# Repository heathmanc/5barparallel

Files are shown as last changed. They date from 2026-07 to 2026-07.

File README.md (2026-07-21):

# Vision-Guided 5-Bar Bung-Cover Robot

Python + OpenCV control for a vision-guided **5-bar parallel-SCARA** pick-and-place
robot that installs plastic battery bung covers into the vent holes of a Group 31
battery on an indexing conveyor. An overhead camera detects holes and loose covers;
Python solves the 5-bar inverse kinematics, validates the target against the
workspace/singularity guard, and hands one pick/place job to a CompactLogix PLC.

See [`Claude.md`](Claude.md) for the full design, the verified geometry, and the
hardware/software responsibility split.

## Screenshots

A PySide6 dark-theme HMI. The **Vision** tab is the main run screen — detected
vent holes (numbered) and loose covers (green = reachable and correctly sized,
red = outside the clean work zone), with live drive / home / PLC / camera status
and the automatic pick-place cycle behind **Start**.

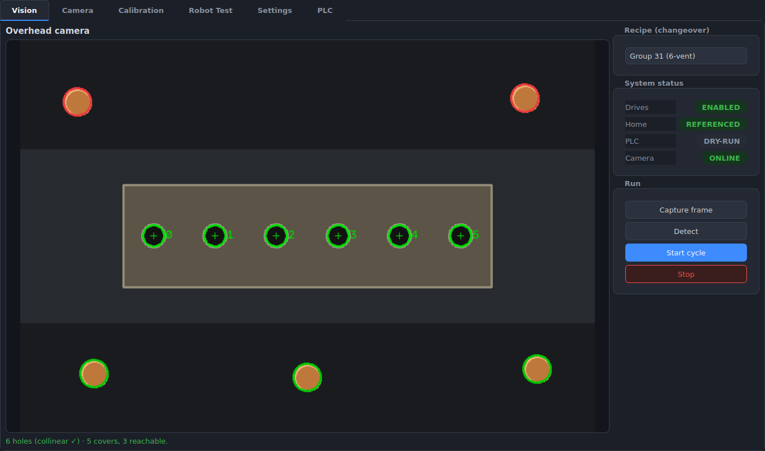
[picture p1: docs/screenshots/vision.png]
Vision tab


|  |  |
|---|---|
| **Calibration** — click known points, fit a per-recipe pixel→robot homography (RMS residual reported) | **Camera** — Basler imaging controls with a live preview |
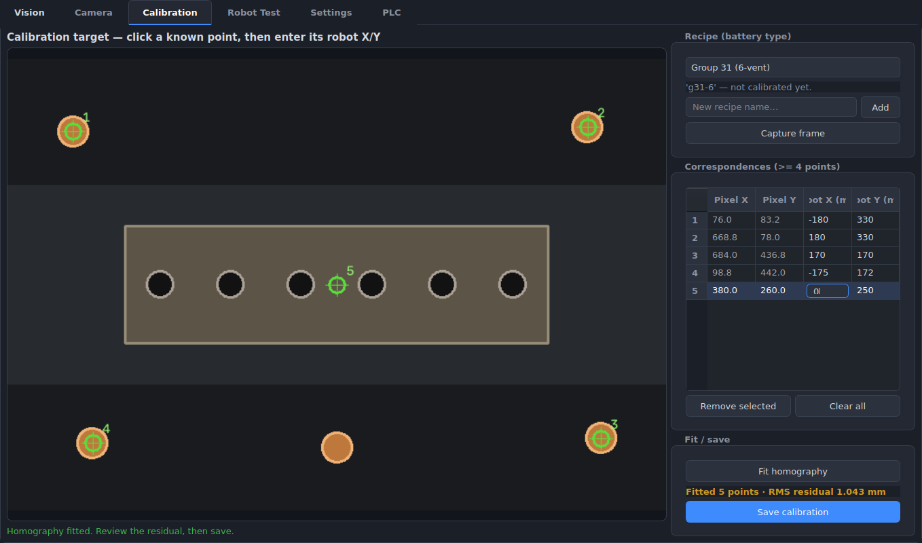
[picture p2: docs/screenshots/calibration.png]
Calibration tab
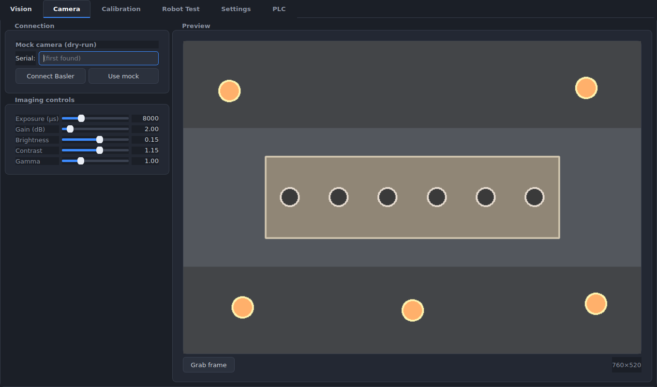
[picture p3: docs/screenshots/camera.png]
Camera tab
|  |  |
| **Robot Test** — reference, teach home, and jog (every move workspace-validated) | **Settings** — geometry + workspace-guard thresholds, re-validated on apply |
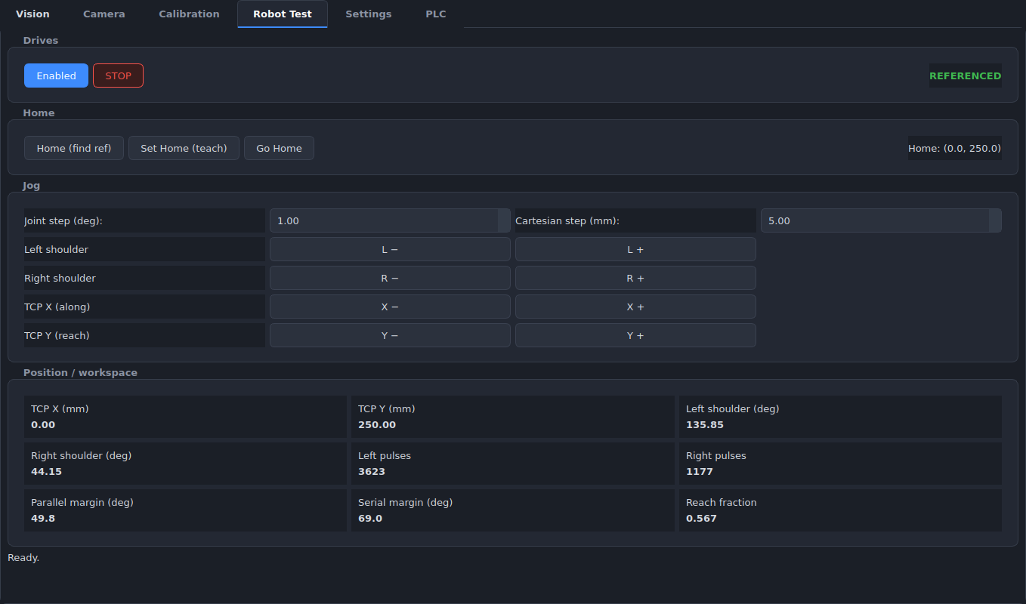
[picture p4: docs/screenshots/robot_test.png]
Robot Test tab
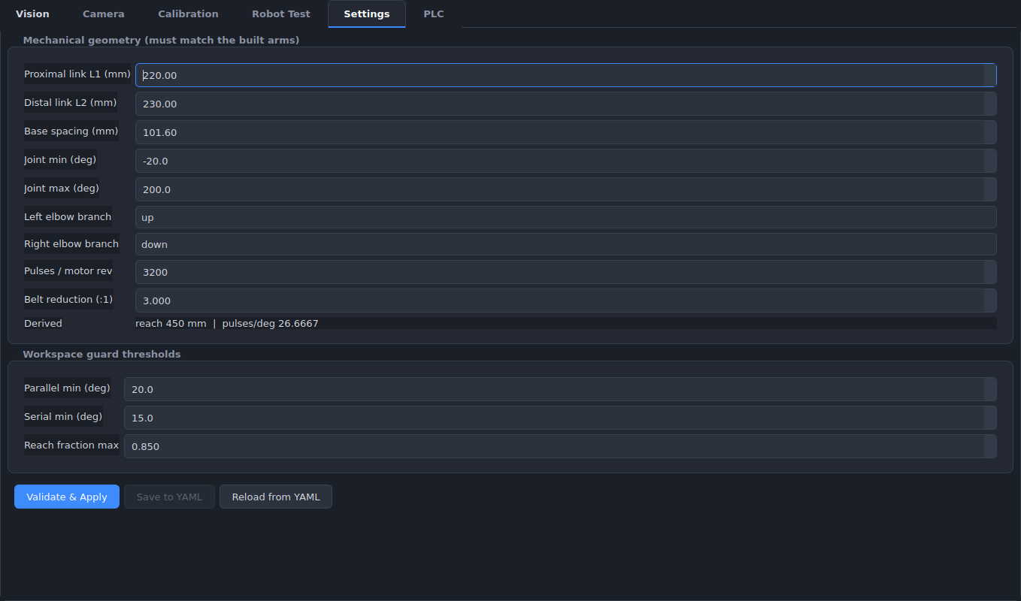
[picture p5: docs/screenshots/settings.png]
Settings tab
|  |  |
| **PLC** — connect a driver at runtime + the full tag contract the Studio 5000 program must implement |  |
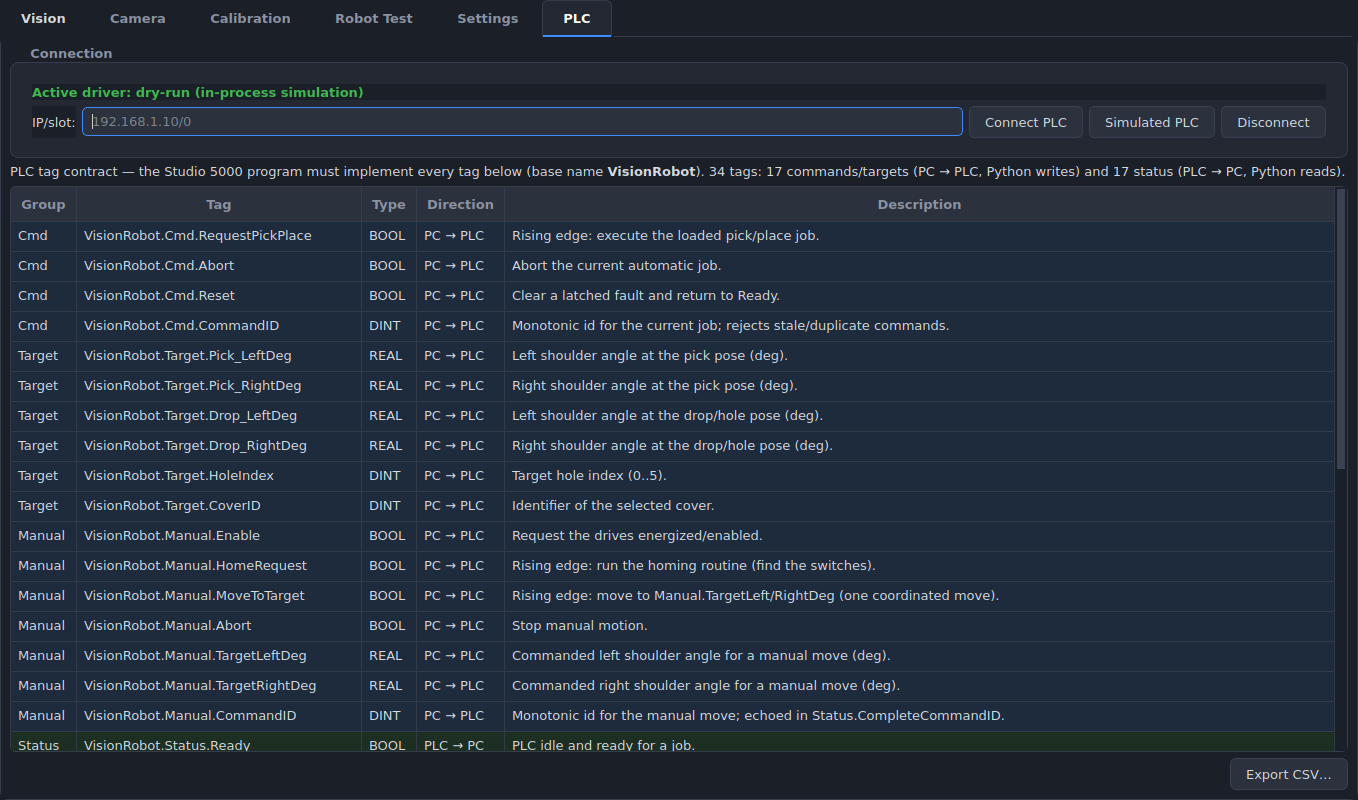
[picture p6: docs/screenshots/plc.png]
PLC tab
|  |  |

## Status

The full pipeline is implemented and tested end-to-end (141 tests) — it runs in
dry-run, against a simulated PLC, or on real hardware:

> **capture → detect (holes + covers) → per-recipe calibration (pixel→robot) →
> workspace/singularity validation → plan pick & drop → PLC pick/place handshake
> → re-image → next hole.**

| Area | Status |
|---|---|
| Kinematics + workspace/singularity guard (`robot/{fivebar_kinematics,workspace}.py`) | done, tested |
| Camera — Basler (pypylon) + mock (`vision/camera.py`) | done, tested |
| Detection — holes (collinear) + covers (quality / size / reachability) (`vision/detect_*.py`) | done, tested |
| Per-recipe calibration + changeover (`vision/calibration.py`, `app/recipes.py`) | done, tested |
| Motion drivers — dry-run + PLC over EtherNet/IP + simulator (`robot/driver.py`, `plc/*`) | done, tested |
| Planner + pick/place handshake (`robot/planner.py`, `plc/handshake.py`) | done, tested |
| Automatic cycle, off the UI thread (`app/cycle_manager.py`, `gui/cycle_worker.py`) | done, tested |
| PySide6 HMI — Vision · Camera · Calibration · Robot Test · Settings · PLC | done, tested |
| CLI entry (`main.py`, `app/launch.py`) | done, tested |
| `app/diagnostics.py` (save annotated fail frames) | deferred |

## Setup

```bash
python -m venv .venv
source .venv/bin/activate          # Windows: .venv\Scripts\activate
pip install -e .[dev]              # installs the package + pytest
```

## Test

```bash
pytest -q
```

The tests encode the design verification from `Claude.md` §3: the whole work zone
(six holes + cap pick point + ±2 in cross-conveyor tolerance) clears every
singularity and reach check.

## Quick use

```python
from bung_cover_robot.robot import FiveBarKinematics, WorkspaceValidator

kin = FiveBarKinematics()             # verified default geometry
validator = WorkspaceValidator(kin)

x, y = 0.0, 250.0                     # robot-frame TCP target (mm)
result = validator.validate(x, y)     # ALWAYS gate on this before the PLC
if result.ok:
    target = kin.inverse(x, y)
    print(target.left_deg, target.right_deg)
else:
    print("rejected:", result.reason)
```

**Rule:** never send a target to the PLC without `WorkspaceValidator.validate()`
returning `ok` (Claude.md §9, §15).

## Camera (Basler)

Native Basler controls are reached through Basler's `pypylon` SDK; frames come
back as OpenCV-native BGR `numpy` arrays. A `MockCamera` provides synthetic
frames so the pipeline runs with no hardware (`--dry-run`).

```python
from bung_cover_robot.vision import (
    open_camera, CameraConfig, CameraControls,
)

config = CameraConfig.from_yaml("config/camera_config.yaml")
controls = CameraControls.from_yaml("config/camera_config.yaml")

# mock=True for dry-run; drop it (or pass mock=False) for a real Basler.
with open_camera(config, controls, mock=True) as cam:
    frame = cam.grab()                       # OpenCV BGR ndarray

    # Exposed controls — by logical name, resolved to the right GenICam node:
    cam.set_control("exposure_time_us", 6000.0)
    cam.set_control("brightness", 0.2)
    cam.set_control("contrast", 1.1)
    cam.set_control("gain", 3.0)
    print(cam.get_control("exposure_time_us"))
```

Logical control names (`brightness`, `contrast`, `exposure_time_us`, `gain`,
`gamma`, `black_level`, `saturation`, `sharpness`, ROI, orientation, …) are
mapped to per-model GenICam nodes in `CONTROL_REGISTRY`; you can also pass a raw
GenICam node name or extra nodes via `CameraControls(extra={...})`. On a real
camera, `BaslerCamera.list_devices()` enumerates connected cameras and
`control_range(name)` returns a control's `(min, max)` for building sliders.

## GUI (robot HMI)

A PySide6 tabbed HMI (see [Screenshots](#screenshots)). Every commanded move is
gated by `WorkspaceValidator` before it reaches the driver.

```bash
pip install -e .[gui]
bung-cover-robot                         # dry-run: in-process sim driver + demo scene
bung-cover-robot --sim-ec                # EtherCAT driver vs a simulated A6 network
bung-cover-robot --ethercat              # real A6 servo drives (IgH EtherCAT master)
bung-cover-robot --camera basler         # real Basler (else the mock demo scene)
bung-cover-robot --config /path/to/config  # config dir (robot/camera/recipes yaml)
```

`--dry-run` / `--sim-ec` / `--ethercat` select the motion backend and `--camera
{auto,mock,basler}` the camera, independently. Also runs as `python -m
bung_cover_robot`.

**Deploying to a real control PC** (IgH EtherCAT master + servos): run
`scripts/install.sh` and follow **[`docs/deploy.md`](docs/deploy.md)** — venv +
app install, rebuilding the RT daemon on the target, passwordless-sudo for the
daemon, and migrating your `config/` (calibration, home, recipes).

**Vision tab** (main screen) — capture, **Detect** (holes + covers with live
reachability), and **Start / Stop** the automatic pick-place cycle. Each pick
re-images (loose covers shift), and the cycle runs on a worker thread so a
multi-second PLC handshake never freezes the HMI. A **Recipe (changeover)**
selector loads the active battery type's calibration + vent-hole count.

**Camera tab** — connect a Basler (or the mock), with exposure / gain /
brightness / contrast / gamma controls written through to the camera and a live
preview.

**Calibration tab** — build a real pixel→robot calibration per recipe: pick the
recipe (or add one), click known points on a captured frame, type their
robot-frame XY, **fit** the homography (≥4 non-collinear points; reports the RMS
residual in mm), and **save**. A saved calibration is adopted by the Vision tab
live when it's the active recipe.

**Robot Test tab:**
- **Drives** — Enable / STOP. Motion is refused while disabled.
- **Home** — *Home (find ref)* runs the hardware homing routine (find the home
  switches) and adopts the reference pose; *Set Home (teach)* captures the
  current pose as the software home; *Go Home* drives back to it. Jogging
  requires the robot to be **referenced** first.
- **Jog** — per-shoulder joint jog (L±, R±) and Cartesian TCP jog (X±, Y± in the
  robot frame), with independent joint-step (deg) and Cartesian-step (mm) sizes.
  *Absolute-incremental*: each press computes a new absolute target, validates
  it, and commands one coordinated move.
- **Position / workspace** — live TCP, shoulder angles, drive pulses, and the
  parallel/serial singularity margins + reach fraction. A jog that would leave
  the clean workspace is rejected with the reason; the robot doesn't move.

**Settings tab** — view/edit mechanical geometry (L1, L2, spacing, joint limits,
branch, drivetrain) and the workspace guard thresholds. *Validate & Apply*
re-runs the full work-zone validation and **refuses** geometry that can't clear
every singularity/reach check (Claude.md §3); *Save to YAML* persists only
validated geometry to `config/robot_config.yaml`.

**PLC tab** — connect/disconnect the motion driver at runtime (dry-run,
simulated PLC, or a real CompactLogix by IP/slot) and a read-only table of the
full tag contract the PLC must implement. To build the Studio 5000 side, start
with **[`docs/plc_setup.md`](docs/plc_setup.md)** — step-by-step bring-up
(network the Teknic ClearLink, import Teknic's CompactLogix example `.L5K`,
create the tags, commission). Reference material: [`docs/plc_program.md`](docs/plc_program.md)
(architecture, UDT, tag contract), [`docs/plc_ladder.md`](docs/plc_ladder.md) and
[`docs/plc_homing.md`](docs/plc_homing.md) (ladder + Structured Text matched to
Teknic's examples), and [`docs/homing.md`](docs/homing.md) (switch placement).

The GUI is a thin view over the headless `RobotTestController`, which drives a
swappable `RobotDriver`:
- `DryRunRobotDriver` — in-process simulation.
- `PlcRobotDriver` — manual jog/home over EtherNet/IP (pycomm3), using the
  `VisionRobot.Manual.*` tag surface (`plc/tags.py`). A `SimulatedPlcClient`
  emulates the ladder so `--sim-plc` runs the real handshake with no hardware.
  To drive a real robot, the Studio 5000 program must implement those tags +
  the homing routine (see the PLC contract note below).

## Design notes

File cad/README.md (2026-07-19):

# cad/ — parametric mechanical design (CadQuery)

`generate.py` regenerates every STEP model and preview image from source. The
geometry is tied to the software's source of truth: link lengths, base spacing,
and the home pose come from `FiveBarConfig` / `FiveBarKinematics`, and the
link-collision proof sweeps the same `WorkspaceValidator` the runtime uses — so
the mechanical design cannot silently drift from the motion software.

```
pip install cadquery        # only needed to regenerate CAD (not for the runtime)
python cad/generate.py      # -> cad/step/*.step, docs/cad/*.png
```

## Level assignment (the "cross" arrangement)

The distal of each side pairs with the proximal of the *other* side:

| plane | z (mm) | members |
|---|---|---|
| A (lower) | 131–161 | proximal **L** + distal **R** |
| B (upper) | 166–196 | proximal **R** + distal **L** |

(The arm planes were raised from the earlier 111/146 so the shoulder bearing
caps + preload locknut fit under the lower arm — the `generate.py` Z-stack is
now derived bottom-up so nothing collides silently.)

Why: the two proximals sit on different planes so they can **never** collide;
the two distals land on adjacent planes so they **stack naturally at the TCP**
(full-height bosses, shared Ø8 pin, one 5 mm spacer — no lap machining). Each
distal shares a plane only with the opposite proximal, and `generate.py`
asserts at build time that those cross pairs keep **> 80 mm** centerline
clearance everywhere the workspace validator allows the TCP to be (beams are
20–22 mm wide; anything above ~24 mm is safe).

Identical parts both sides: the right proximal simply clamps higher on the
shoulder shaft's long D-flat; the distals are the same part.

## Design table

| Item | Spec |
|---|---|
| Links | 6061-T6 pocketed-I from 30 mm plate (or PA12/PA-CF print for bring-up) |
| Proximal (L1=200) | I 30×22, fl 3.5 / web 4.0 — Ø25 D-bore + M5 set screw at shoulder, 688 pockets at elbow. ~214 g Al / 80 g PA12 |
| Distal (L2=230) | I 30×20, fl 3.0 / web 3.5 — Ø8 split clamp at elbow (slit into the bore, 2× M3 pinch bolts), 688 pockets at TCP. ~174 g Al / 65 g PA12 |
| Shoulder shafts | Ø25 h6 × 205, one D-flat from below plane A through the top (serves both clamp heights) |
| Shoulder bearings | 4× **7005 angular-contact** (25×47×12), back-to-back pair per shaft, light preload. Each race sits **flush** in its 12-thick plate (plate = race width) and is trapped by a **flat printed Ø72 cap on the top AND bottom face**, bolted together on a Ø58 BCD (4× M4×30 + nyloc, ≥1.5d rim); each cap's 0.3 mm proud pad presses the outer race only, so the disc seats on the plate with a defined clamp crush. Shaft preload via a locknut above the upper cap. |
| Elbow bearings | 688-2RS (8×16×5) in the proximal elbow pockets; Ø8 × ~75 mm pins with a **bottom head + printed top clip** so no link can walk off (the flipped lower distal included) |
| TCP joint | Hollow spindle Ø20 OD / Ø16 bore in **2× 6804-2RS (20×32×7)** — one in each distal's outer face for max span. The spindle's **bottom flange + top collar** capture both stacked distals. A miniature air cylinder (default ISO 6432 Ø10, Ø15 barrel — set `CYL_BARREL_OD`) drops through the spindle; the cup sits ON the joint axis, immune to the platform's free spin. |
| Drive | HTD-5M 3:1 — 24T (Ø19 bore, on the motor) → 72T (Ø25 bore); belt **450-5M-15**, C = 97.5 mm. 24T (up from 20T) leaves ~6 mm hub wall over the motor-shaft keyway (asserted ≥ 3.5). |
| Belt planes | left z5–20, right z25–40 (72T pulleys stagger to pass at 80 mm spacing) |
| Motors | 2× StepperOnline A6M80-750 under the deck, shafts up, **behind the shoulders** (belts run rearward). Splayed out by 16° from −Y so the two 80-frame bodies clear each other — approximately-behind, not exactly on each shaft axis. |
| Motor mounts | **Jackscrew slider on a cradle:** each motor bolts (from below) to a carriage that slides on a fixed window-frame **cradle** directly beneath it. The cradle's two **solid shear-fin walls** (9.5 thick, guide face to frame edge) rise to the deck underside and bolt to it (3× M5 per fin, full-depth heat-sets); four M5 lock bolts pass through ±6 mm slots in the carriage into tapped bosses in the cradle frame **right below** the slots. An M6 jackscrew through the cradle's integral block pushes the carriage away from the shoulder to tension. Fins/bolts/block stay outside the belt corridor and **inside the deck outline** (all asserted in `params.check_layout()`). Machine-shop sheets: `cad/drawings/bcr_drawing_set.pdf`. |
| Plates | bottom **deck** 294 × 240 × 12 (fits a 300×300 bed; covers every underside part; only deliberate holes — full coordinate table on drawing BCR-04), top plate 156 × 92 × 12 (12 thick = race width; standoffs moved to ±64, ±36 to clear the Ø72 caps) |

## Placeholders to resolve at build time

- Motor flange modeled as the standard 80-frame pattern (Ø70 pilot / Ø90 BCD /
  4×Ø6.6, Ø19×38 shaft, body length approximate) — **verify against the boxed
  A6M80 datasheet before drilling**.
- Pulleys and belts are dimensionally-correct blanks — swap vendor STEPs.
- Bearings are plain rings (no rolling elements); 7005 pairs need back-to-back
  orientation and preload via shim + locknut.
- The carriage + cradle are dimensioned on drawing sheets BCR-02/03. Confirm
  the carriage bolt pattern against the boxed motor before fitting inserts.
- The bearing caps trap the outer race (flush race, 0.3 mm pad crush); set the
  running preload with a ground shim + the shaft locknut.
- The deck is a single 294×240 piece that fits a 300×300 bed; if your bed is
  smaller, split it on the mid-line with a bolted lap.

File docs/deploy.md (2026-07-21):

# Deploying to a control PC

How to move this project onto a new **control PC** — the Linux machine that
drives the two A6 servos over EtherCAT and runs the HMI. (For a sim/office PC
with no robot, skip everything EtherCAT: `scripts/install.sh --no-daemon`, then
`python -m bung_cover_robot --sim-ec`.)

The move splits into three kinds of thing, and only the first is a real
"packaging" step:

| Piece | How it moves | Notes |
|---|---|---|
| **Python app** (`src/`) | `git clone` + `scripts/install.sh` | Standard package; a venv + `pip install` per machine. |
| **`config/`** — robot geometry, home, **calibration**, recipes, tuning | **Copy the folder** | Your machine's *state*. Copy it from the old PC (or recalibrate on a different robot). |
| **IgH RT daemon** (`igh/ec_master_daemon`) | **Rebuilt on the target** | A C binary linked against this machine's IgH EtherLab master — never copied. `install.sh` builds it. |
| **IgH EtherLab master + RT kernel + NIC** | **Provisioned once** | OS-level platform build, not something you package. See the references below. |

There is no single shippable bundle, because half of it is compiled against the
target's kernel + EtherCAT master. Don't reach for PyInstaller: it would bloat
with PySide6/OpenCV and still can't bundle the IgH-linked daemon or the master.

---

## 0. Platform prerequisites (one-time, per machine)

Do these first — they're the OS build the app sits on. Both are already
documented; don't duplicate them, follow them:

- **RT kernel, NIC pinned to `ecat0`, CPU isolation** → `docs/ethercat_bringup.md` §1.
- **Install the IgH EtherLab master** (the maintained fork, generic driver) and
  prove the drive enumerates (`ethercat slaves` lists the AS715N) →
  `igh/README.md` §1. **Milestone: `ethercat slaves` shows the drive.** Until
  that works, nothing below will move the robot.

You also need the build toolchain: `sudo apt install -y build-essential python3-venv`.

---

## 1. Get the code + install

```bash
git clone <repo-url> 5barparallel        # or copy the repo over
cd 5barparallel
scripts/install.sh                       # venv + app + build the daemon
#   --etherlab /opt/etherlab   (default)  IgH install prefix
#   --from-lock                           install pinned versions (see §5)
#   --test                                run the suite after installing
```

`install.sh` creates `.venv`, installs the app with the GUI + vision extras
(`pip install -e .[gui,vision]`), builds `igh/ec_master_daemon` against the IgH
master, freezes a `requirements.lock`, and prints the remaining manual steps.
Re-run it after every `git pull` — it rebuilds the daemon, which you **must** do
whenever its shared-memory ABI changes (the app refuses a stale daemon with
`daemon ABI N != M — rebuild it`).

---

## 2. Let the app launch the daemon (passwordless sudo)

The RT daemon must run as root (raw sockets + `mlockall` + SCHED_FIFO). The app
launches it for you with `sudo -n ec_master_daemon …` — the `-n` means it will
**never prompt**, so from the GUI (no TTY) it fails fast unless sudo is
password-free for exactly that binary. Add a drop-in:

```bash
sudo tee /etc/sudoers.d/bcr-ethercat >/dev/null <<EOF
# Let the HMI user start the EtherCAT RT daemon without a password.
$USER ALL=(root) NOPASSWD: $PWD/igh/ec_master_daemon
EOF
sudo chmod 440 /etc/sudoers.d/bcr-ethercat
sudo visudo -c        # validate
```

(If you'd rather not use sudo at all, start the daemon yourself before the app —
`sudo igh/ec_master_daemon --drives 2` — and the app attaches to its shared
memory. The sudo path is just the convenience default.)

---

## 3. Bring your calibration/config across

`config/` holds everything machine-specific — geometry, the home datum, the
per-recipe pixel→robot **calibration** and ROI, detection sliders, camera and
motion tuning. Copy it from the old PC:

```bash
rsync -a old-pc:/path/to/5barparallel/config/ ./config/
```

- **Same robot, new PC** → keep the calibration; it's tied to the arm geometry
  and camera mount, not the PC.
- **Different robot** → recalibrate (Calibration tab) and re-teach home; the
  geometry and encoder datum differ.

Encoder note: this build uses **bounded-linear multi-turn absolute** encoders,
so the home datum survives power-off — but the software still requires a **Set
Home on each program launch** (`is_referenced` starts false). First launch on the
new PC, re-home once. (See `docs/ethercat_bringup.md` on `C00.07` / linear mode.)

---

## 4. First run (do it in this order)

```bash
source .venv/bin/activate
python -m bung_cover_robot --sim-ec                    # 1) no hardware — proves the stack
python -m bung_cover_robot --ethercat --camera basler # 2) real drives + camera
#   --config /path/to/config   if config lives outside the repo
```

Then walk the **first-motion checklist** in `docs/ethercat_bringup.md` §6 (enable
→ Set Home → a slow single move → the demo) before running a production cycle.
Reminder on Stop behavior: the main-screen **Cycle Stop is graceful** (finishes
the current pick, then halts); the Drives-tab bench **demo Stop is a hard stop**.

---

## 5. Reproducible re-installs (the lockfile)

`pyproject.toml` uses `>=` minimums, so a fresh `pip install` could pull newer
PySide6/OpenCV than you validated. `install.sh` writes a `requirements.lock`
(exact `pip freeze`) on install. **Commit it.** To reproduce that exact
environment on the next PC — or to roll back a bad upgrade:

```bash
scripts/install.sh --from-lock
```

Regenerate the lock deliberately (not accidentally) when you *want* to move
versions: run a plain `scripts/install.sh`, test, then commit the new lock.

---

## 6. Optional: start the HMI on boot (kiosk)

For a fixed control station, autostart the HMI as the logged-in operator user
(it needs the graphical session for Qt + a display). Example systemd **user**
unit — `~/.config/systemd/user/bcr-hmi.service`:

```ini
[Unit]
Description=Bung-cover robot HMI
After=graphical-session.target
PartOf=graphical-session.target

[Service]
Type=simple
WorkingDirectory=%h/5barparallel
ExecStart=%h/5barparallel/.venv/bin/python -m bung_cover_robot --ethercat --camera basler
Restart=on-failure

[Install]
WantedBy=graphical-session.target
```

```bash
systemctl --user enable --now bcr-hmi.service
```

Leave the **daemon** to the app's auto-launch (§2) rather than a separate unit —
`IgHMaster` owns its lifecycle (start, ABI check, shutdown) and refuses to run
against a mismatched one.

---

## Troubleshooting

| Symptom | Cause / fix |
|---|---|
| `IgH daemon exited immediately … sudo: a password is required` | The sudoers drop-in (§2) is missing or the path doesn't match `$PWD/igh/ec_master_daemon`. |
| `daemon ABI N != M — rebuild it` | Stale daemon after a pull. `make -C igh ETHERLAB=/opt/etherlab` (or re-run `install.sh`), then `sudo pkill ec_master_daemon`. |
| `IgH daemon not built` | Run `scripts/install.sh` (or `make -C igh …`). Needs libethercat — see §0. |
| `ethercat slaves` doesn't list the drive | Master/NIC problem, not the app — MAC/interface/generic-driver. `igh/README.md` §1, `dmesg \| grep -i ethercat`. |
| Move ends "did not settle", off by a multiple of 131072 counts | Multi-turn datum offset — set the encoder to **bounded linear** mode. `docs/ethercat_bringup.md` (C00.07). |
| Drive drops to SWITCH ON DISABLED, no fault | Power-stage/E-stop chain blip — `docs/ethercat_bringup.md` §4d. |

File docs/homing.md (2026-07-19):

# Homing & limit switches

Reference for the 5-bar's home and travel-limit switches. The verified values
live in `config/robot_config.yaml` under the `homing:` block and load via
`bung_cover_robot.robot.HomingConfig`; the PLC homing routine and the GUI's
**Home (find ref)** read them instead of hard-coding.

Overhead placement of home + limit switches

## Why homing is required

The Leadshine 57HS22-07 steppers are **open-loop** — on every power-up the
controller has no absolute position, so each shoulder must be homed to a switch
before jogging or running. Because of the **3:1 belt reduction**, the home flag
must sense the **shoulder** rotation, not the motor shaft (a motor-side flag is
3× ambiguous).

## Flag on the proximal link (L1), never the distal (L2)

The 72T output pulley and the **proximal link L1** are one rigid body about the
shoulder pivot, so a small flag **tab on L1** carries the exact 1:1 joint angle —
and is easier to fabricate than a pulley feature.

- **Flag L1 (proximal).** In a 5-bar the **distal link L2 floats** (its
  orientation depends on *both* shoulder angles), so an L2 flag has no single
  home angle — never flag L2.
- **Flag radius `flag_radius_mm = 40`.** Close to the hub → short, stiff sensor
  bracket. A larger radius improves angular repeatability (prox ~0.1 mm ≈ 0.14°
  at r=40 vs ~0.057° at r=100) at the cost of a longer bracket; 40 mm is the
  chosen balance. For tighter homing without moving the flag, use an optical slot
  sensor and/or a two-stage (fast-approach → back-off → slow-reapproach) home.

## Trip angles & coordinates (robot frame, mm)

Both shoulders share the same trip angles (CCW from +X). Marker = flag/sensor
position at `base + r·(cos θ, sin θ)` with `r = 40 mm`.

| Switch | Trip angle | Left L1 flag | Right L1 flag |
|---|---|---|---|
| Min hard limit | −20° | (−2.4, −13.7) | (+77.6, −13.7) |
| **Home reference** | L 140.54° / R 39.46° | (−70.9, +25.4) | (+70.9, +25.4) |
| Max hard limit | +200° | (−77.6, −13.7) | (+2.4, −13.7) |

Pivots: left base (−40, 0), right base (+40, 0). Home reference pose is the
centred, well-conditioned TCP **(0, 250)** (arms splayed left-up/right-down,
clear of the parallel-singularity band).

## Home is mid-travel — read it only during homing

Across the work zone the **left shoulder sweeps ~93°→188°** and the **right
~−8°→87°**, so the home angle (140.54° / 39.46°) sits mid-travel and the flag
**passes the sensor during normal motion**. That is fine: the PLC reads the home
switch **only during the homing routine** and ignores it otherwise. (If you later
want the home switch to double as a live position check, move the home pose
outside the working band instead.)

## Homing sequence (PLC-owned, Claude.md §7)

1. Enable drives.
2. Drive each shoulder toward its home switch from one consistent direction.
3. On trigger, back off and re-approach slowly for repeatability.
4. Set the reference to the home angle (L 140.54° / R 39.46°); report it in
   `VisionRobot.Status.ActualLeft/RightDeg`, set `VisionRobot.Status.Homed`.
5. Soft limits (−20°…+200°) become active.

Python side: `RobotTestController.home_reference()` → `RobotDriver.home()` →
(for a real robot) `PlcRobotDriver` pulses `VisionRobot.Manual.HomeRequest` and
waits for `Homed` (Claude.md §11).

## Switch selection & wiring

- **Home sensor:** inductive proximity (repeatable, non-contact) or optical slot
  sensor; one per shoulder, body on a short base bracket, target tab on L1.
- **Hard limits:** min (−20°) and max (+200°) per shoulder, wired into the drive
  **ENABLE / fault chain** (and/or ClearLink limit inputs) so they act even if
  the PLC logic hangs. `limit_min_deg` / `limit_max_deg` mirror `joint_limits` in
  the config; the software jog guard uses `joint_limits`, these document the
  physical switch angles for the PLC.

## Config block

```yaml
homing:
  home_left_deg: 140.5406
  home_right_deg: 39.4594
  home_tcp_mm: [0.0, 250.0]
  flag_radius_mm: 40.0
  limit_min_deg: -20.0
  limit_max_deg: 200.0
```

The figure above is regenerated to scale from the verified geometry; the SVG
(`docs/homing_placement.svg`) is editable for markup.

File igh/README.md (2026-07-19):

# IgH EtherCAT master — DC go/no-go test

Purpose: prove whether the **IgH EtherLab** master can bring the ANCTL AS715N
(StepperOnline A6-EC) to OP with **distributed clocks** and no `Er74.1`/`0x8700`
"No sync signal" — the fault pysoem can't get past. This is a *test only*; the
full `IgHMaster` backend comes after it passes.

`igh_test.c` is the direct analog of `scripts/ec_dc_probe.py`, in IgH's C API.

---

## 1. Install the IgH master (once)

Use the **maintained** fork — the old etherlab.org 1.5.2 won't build on a 6.12
kernel. Build with the **generic** driver so it rides the existing `e1000e` NIC
(no special EtherCAT NIC driver needed).

```bash
sudo apt install -y build-essential autoconf libtool pkg-config \
     linux-headers-$(uname -r) git

cd ~
git clone https://gitlab.com/etherlab.org/ethercat.git igh-ethercat
cd igh-ethercat
./bootstrap
./configure --prefix=/opt/etherlab \
            --enable-generic --enable-userlib \
            --disable-8139too --disable-eoe
make -j"$(nproc)"
make modules
sudo make install
sudo make modules_install
sudo depmod
```

Point the master at the EtherCAT NIC (the MAC we pinned to `ecat0`) with the
generic driver. **The config lives under the install prefix**, i.e.
`/opt/etherlab/etc/sysconfig/ethercat` (NOT `/etc/sysconfig`):

```bash
sudo tee /opt/etherlab/etc/sysconfig/ethercat >/dev/null <<'EOF'
MASTER0_DEVICE="04:92:26:bd:5f:fe"
DEVICE_MODULES="generic"
EOF
```

The `ethercat` tool is at `/opt/etherlab/bin` — add it to PATH. Take the EtherCAT
port off the IP stack (IgH's generic driver talks to the MAC directly), then start
the master and confirm the drive enumerates:

```bash
export PATH=$PATH:/opt/etherlab/bin
sudo ip link set ecat0 down
sudo /etc/init.d/ethercat start    # (install put the script at /etc/init.d/ethercat)
sudo ethercat master               # master "up", link "UP"
sudo ethercat slaves               # <-- must list the AS715N (0x00400000 / 0x0715)
```

> **`ethercat slaves` showing the drive is milestone #1.** If it doesn't appear:
> the MAC is wrong, the interface is down, or the generic module didn't bind —
> `dmesg | grep -i ethercat` will say which.

## 2. Build + run the DC test

```bash
make -C ~/5barparallel/igh ETHERLAB=/opt/etherlab
sudo ~/5barparallel/igh/igh_test
```

It reaches OP with DC and prints once a second for ~12 s:

```
t= 0s  status=0x0250  err=0x0000  pos=...  al_states=0x08  cycles=...
```

**Interpretation (milestone #2 — the real go/no-go):**

- **`err=0x0000`, `status` = switch-on-disabled (`0x0250`), `al_states=0x08` (OP)
  held for the whole run** → IgH drives this drive's DC correctly. **Path proven**
  — we build the `IgHMaster` backend behind the `EtherCatMaster` interface.
- **`err=0x8700`** → the sync fault persists even on IgH. Then it's not a master
  problem and we rethink (drive/ESI, or hardware).

## Knobs if it doesn't reach OP / DC won't lock

- **`ASSIGN_ACT` (0x0300)** in `igh_test.c` is the DC *AssignActivate* word. It's
  from the drive's **ESI XML** (`<Dc><OpMode><AssignActivate>`). 0x0300 is the
  common CoE value; if DC won't activate, get the real value from the A6-EC ESI
  file and set it here.
- **`SYNC0_SHIFT`** — try `CYCLE_NS/2` if the drive wants margin.
- **`CYCLE_NS`** — 2 ms is safe; the drive's SYNC0 range is mode-dependent.
- If `ethercat slaves` shows the drive but `slave_config` fails, double-check
  `VENDOR`/`PRODUCT` against `ethercat slaves -v`.

---

Report back the per-second lines (especially `err=` and `al_states=`) and whether
`ethercat slaves` listed the AS715N. That tells us go or no-go on IgH.

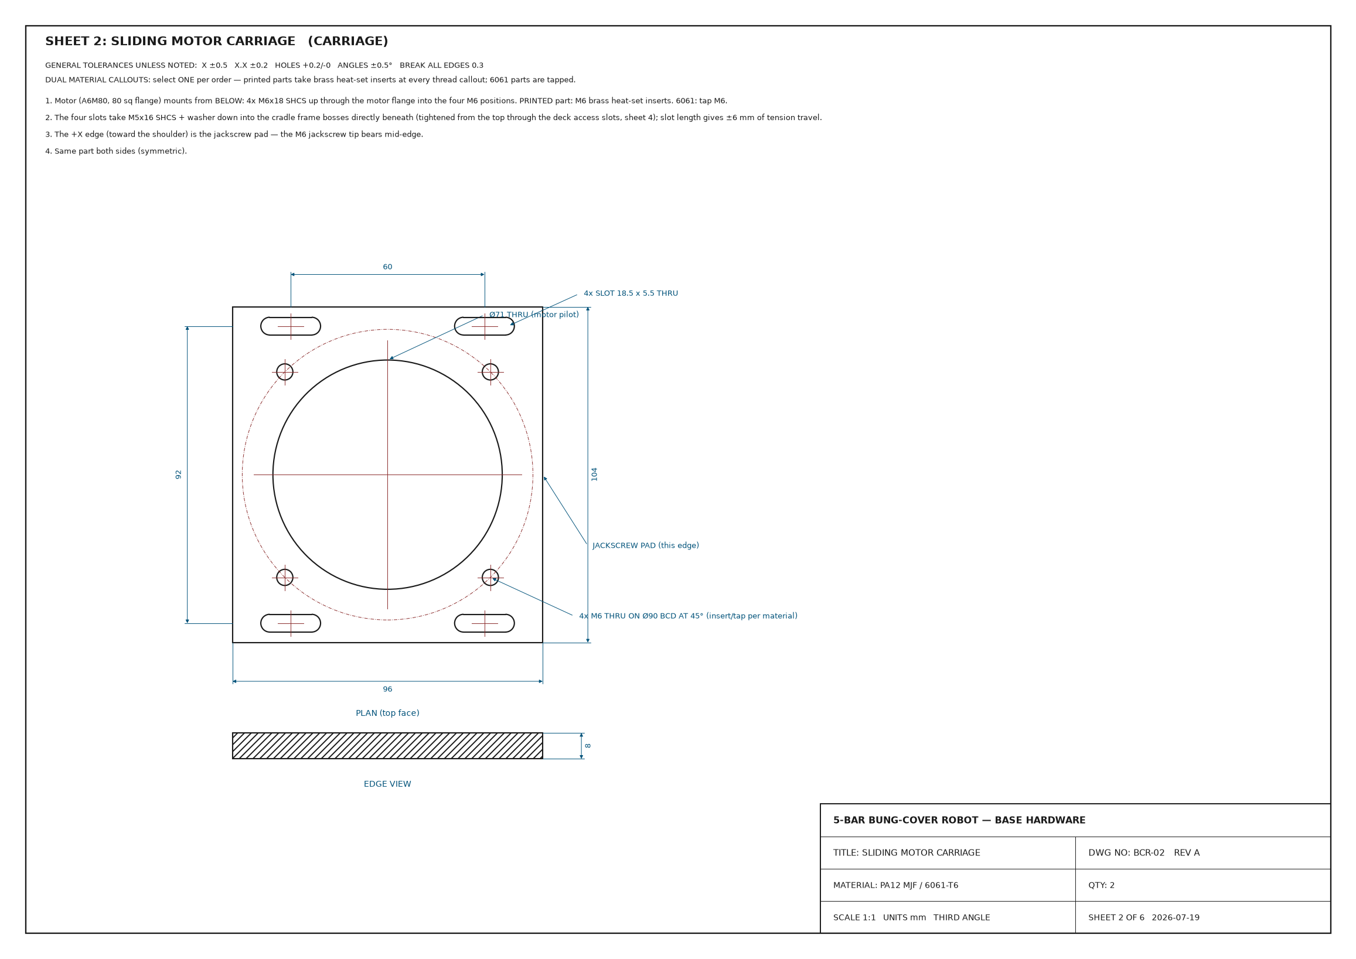
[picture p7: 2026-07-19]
docs/cad/drawings/sheet2_carriage.png

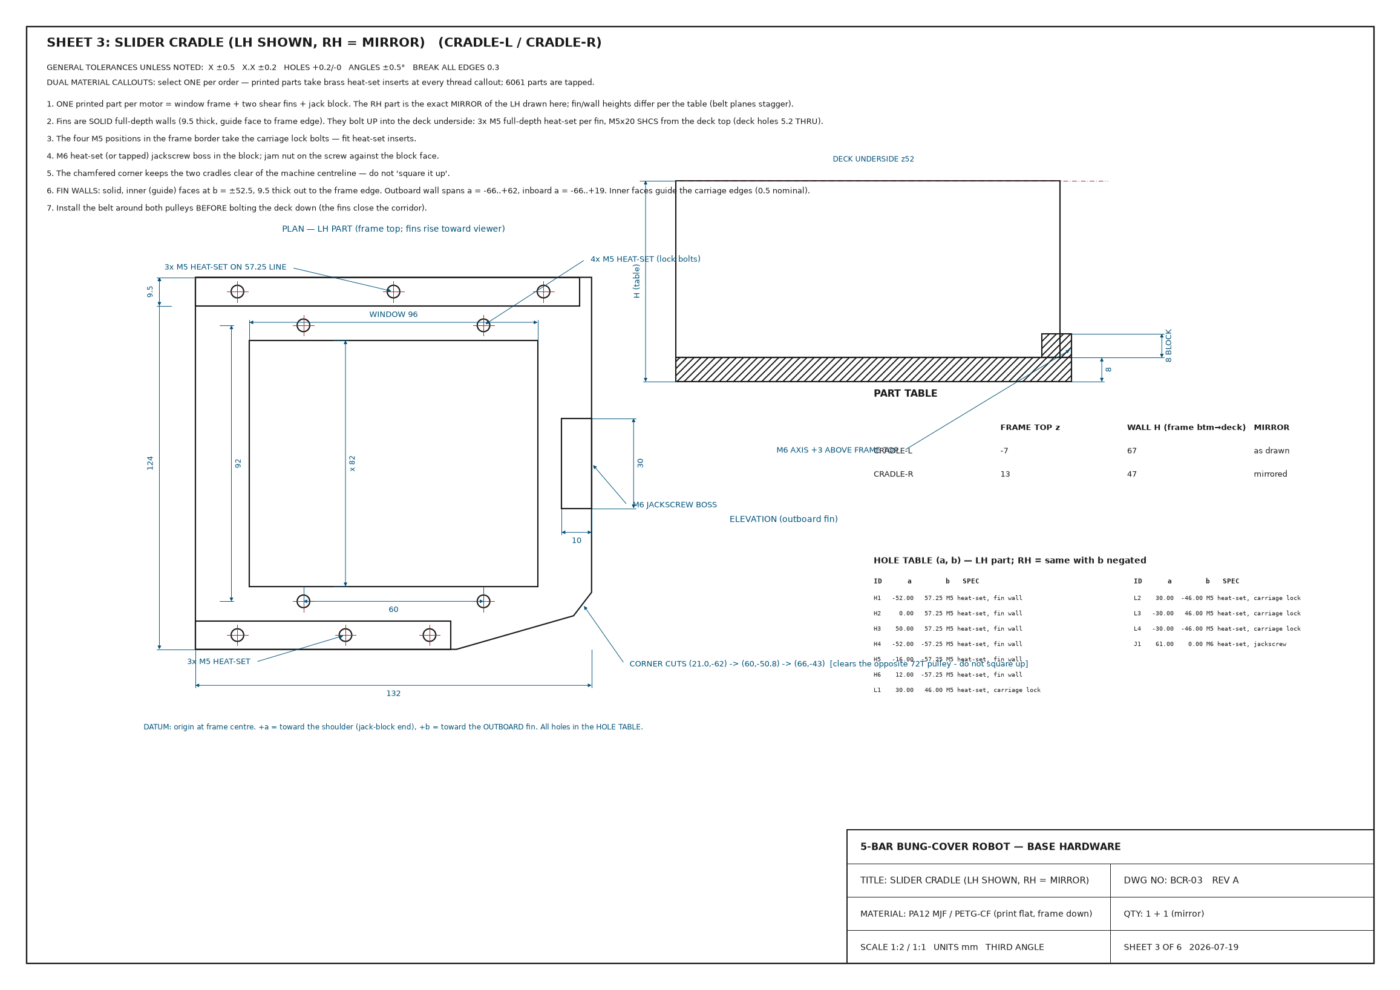
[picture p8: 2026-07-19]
docs/cad/drawings/sheet3_cradle.png

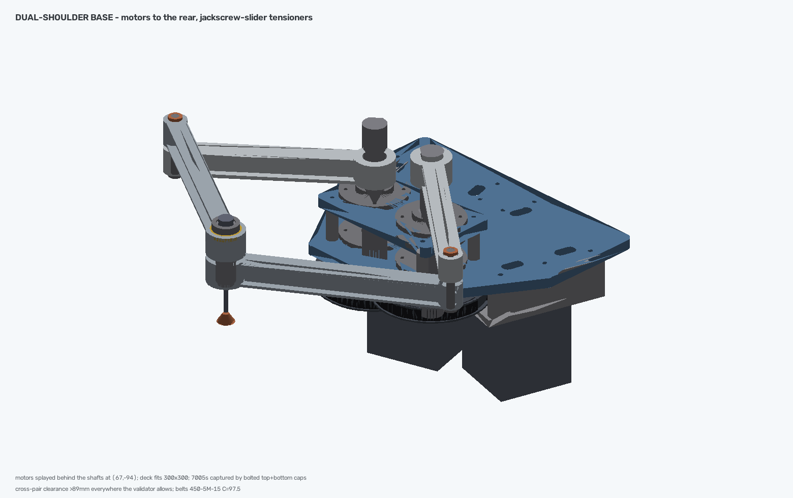
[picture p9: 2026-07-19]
docs/cad/base_iso.png

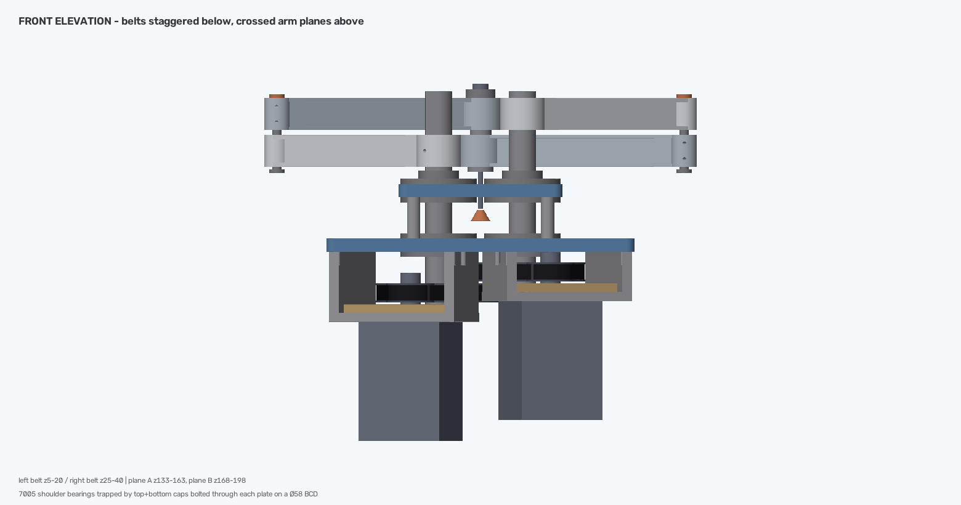
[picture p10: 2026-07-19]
docs/cad/base_front.png

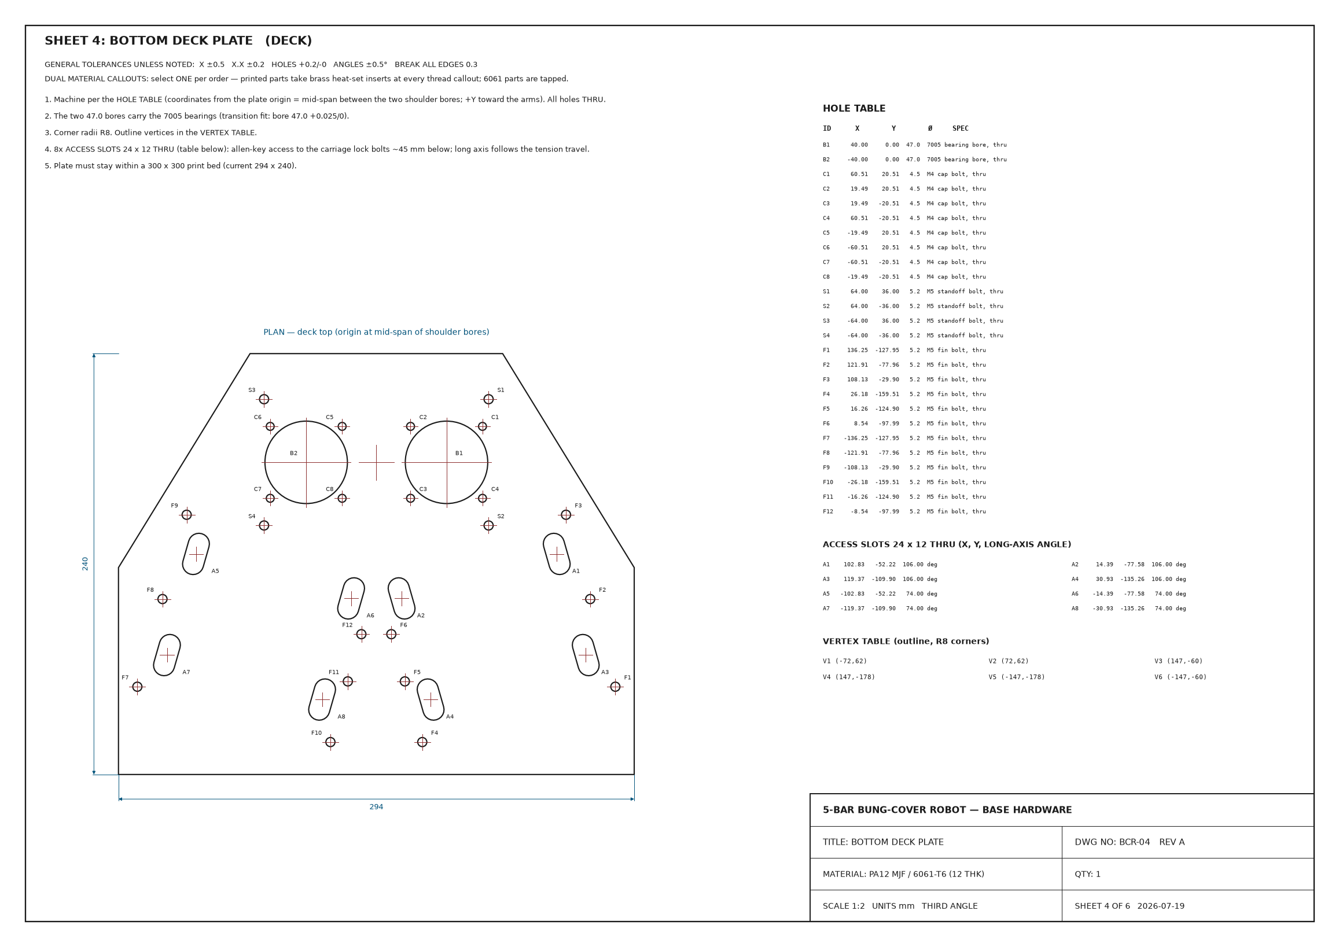
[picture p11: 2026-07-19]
docs/cad/drawings/sheet4_deck.png

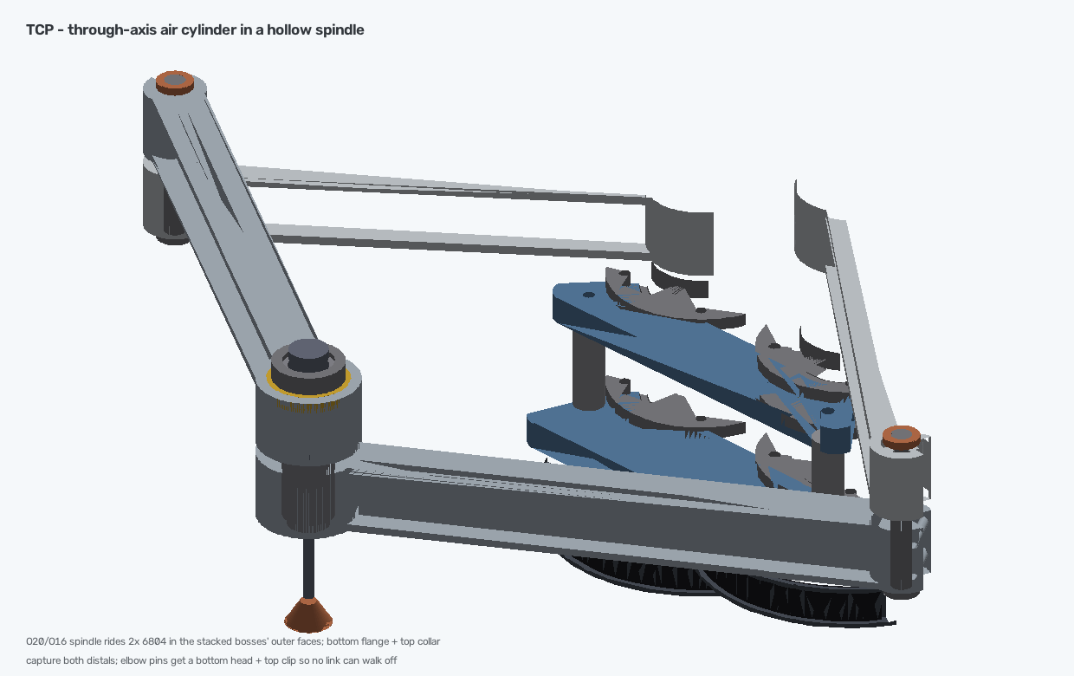
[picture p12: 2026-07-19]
docs/cad/tcp_closeup.png

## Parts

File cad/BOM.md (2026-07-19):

# Mechanical BOM — 5-bar arm hardware

Quantities are **per robot** (two shoulders, two arms of each link). Small
bearings/pins are cheap in 10-packs — buy spares. Links are *starting points*
(commodity parts, many equivalent vendors); confirm price/stock/tolerance before
ordering. Prices omitted deliberately — they drift.

The **motors** (2× StepperOnline A6M80-750, EtherCAT) are specced separately and
are not in this list.

## Bearings

| Qty | Part | Size | Where it goes | Link |
|---|---|---|---|---|
| **4** | **7005** angular-contact | 25×47×12 | Shoulder axles — a back-to-back (DB) **pair per shaft**, lightly preloaded | [VXB 7005B](https://vxb.com/products/7005b-bearing-angular-contact-ball-bearing-25x47x1) · [Amazon](https://www.amazon.com/Bearing-Angular-25x47x12-Bearings-VXB/dp/B002UE8CW2) |
| **4** | **688-2RS** | 8×16×5 | Proximal elbow bosses (2 per elbow) on the Ø8 elbow pins | [Amazon 10-pk](https://www.amazon.com/Bearing-688-2RS-Miniature-Bearings-VXB/dp/B002BBQCMQ) |
| **2** | **6804-2RS** | 20×32×7 | TCP — one in each distal boss, on the hollow spindle | [Amazon (NSK)](https://www.amazon.com/NSK-6804-2RS-Bearing-20x32x7-Shielded/dp/B07WTQ9WMN) · [FastEddy](https://www.fasteddybearings.com/20x32x7-rubber-sealed-bearing-6804-2rs/) |

> **7005 preload:** the pair must mount **back-to-back** with a small axial
> preload (a ground spacer + locknut, or buy a *matched DB set*). A random pair
> of singles gives you no defined preload — that's where the shoulder stiffness
> comes from. For the printed prototype, plain 6005-2RS deep-groove (25×47×12,
> same envelope) is a cheaper stand-in if you don't want to fuss preload yet.

## Shafts & pins

| Qty | Part | Spec | Note | Link |
|---|---|---|---|---|
| **2** | Shoulder shaft | Ø25 h6 × ~205 mm, steel/SS | **Semi-custom:** cut from 25 h6 ground stock, machine the long D-flat + a locknut thread at the top (see `shoulder_shaft.step`) | [Motedis 25 h6](https://www.motedis.com/en/Precision-shaft-25-mm-h6-steel-hardened-and-ground?products_id=6500) · [Ondrives](https://www.ondrivesus.com/precision-ground-stock-saw-cut-ends/metric) |
| **2** | Elbow pin | Ø8 × ~75 mm, hardened, w/ head | Ø8 shoulder screw (head = bottom retention) or a DIN 6325 dowel + a clip both ends | [McMaster 8 mm dowel](https://www.mcmaster.com/products/dowel-pins/diameter~8-mm/) · [Huyett DIN 6325](https://www.huyett.com/dowmh-080-060) |
| **1** | TCP spindle | Ø20 OD / Ø16 bore × ~75 mm, w/ flange | **Custom turned part** — see `dual_base_full.step` (`tcp_spindle`). Start from Ø20 tube/bar | (machine shop / lathe) |
| — | TCP collar | Ø28 clamp collar, Ø20 bore | Off-the-shelf shaft collar retains the spindle | [McMaster shaft collars](https://www.mcmaster.com/products/shaft-collars/) |

## Drive train (HTD-5M, 3:1) — Beltingonline (bepltd) has the whole set

| Qty | Part | Spec | Note | Link |
|---|---|---|---|---|
| **2** | 72T shoulder pulley | 72-5M-15, pilot bore | Bore to Ø25 + keyway to the shoulder shaft | [72-5M-15](https://bepltd.com/products/72-5m-15-htd-pilot-bore-5m-timing-belt-pulley-72-tooth-x-15mm-wide) |
| **2** | 24T motor pulley | 24-5M-15, pilot bore | Bore to Ø19 + keyway to the A6 shaft | [24-5M-15](https://bepltd.com/products/24-5m-15-htd-pilot-bore-5m-timing-belt-pulley-24-tooth-x-15mm-wide) |
| **2** | Belt | 450-5M-15 (90T) | The stock length the layout was solved to (C = 97.5 mm with 24/72) | [450-5M-15](https://bepltd.com/products/450-5m-15-htd-5m-timing-belt-450mm-long-x-15mm-wide) |

> **Motor-pulley keyway:** the drive was moved from 20T/60T to **24T/72T** (same
> 3:1) specifically to give the Ø19 motor-shaft pulley room for the keyway. The
> 24-5M-15's larger pitch dia (38.2 mm) leaves ~6 mm of hub wall over the keyseat
> vs the 20T's ~3 mm — `cad/generate.py` asserts this wall stays ≥ 3.5 mm, so a
> future tooth-count change can't silently reintroduce a paper-thin boss. Still
> confirm the vendor's actual boss OD when ordering the pilot-bore blank.

## Printed structure (see `cad/drawings/bcr_drawing_set.pdf` for shop sheets)

| Qty | Part | STEP / sheet | Note |
|---|---|---|---|
| 2 | Motor carriage | `motor_carriage.step` / BCR-02 | Slides on the cradle; M6 inserts for the motor, 4 lock slots |
| 1+1 | Motor cradle L + R | `motor_cradle_L/R.step` / BCR-03 | RH mirrors LH; frame + 2 shear fins + jack block, one print each |
| 8 | Bearing cap Ø72 | `bearing_cap.step` / BCR-01 | Top + bottom of each 7005 bore, bolted through the plate |
| 1 | Bottom deck | BCR-04 | 294 × 240 × 12 — hole coordinate table on the sheet |
| 1 | Top plate | BCR-05 | 156 × 92 × 12 (+4 Ø12×40 standoffs) — 12 thick = 7005 race width so the race sits flush; widened so the Ø72 caps sit fully on it |

## Fasteners (McMaster-Carr — stable catalog)

| Qty | Part | Use |
|---|---|---|
| 8 | M6 × 18 SHCS (Ø90 BCD) | Motor flange → carriage, fitted **from below** through the flange into M6 inserts/taps in the carriage (full 8 mm engagement) |
| 2 | M6 × 40 jackscrew + jam nut | Belt tensioner — through the cradle's block, tip pushes the carriage pad |
| 8 | M5 × 16 SHCS + washer | Carriage lock bolts — through the ±6 mm slots into M5 inserts in the cradle frame (4 per side) |
| 12 | M5 × 20 SHCS | Cradle fin walls → deck underside (3 per fin, deck holes Ø5.2 thru, full-depth heat-sets in the solid walls) |
| 16 | M4 × 30 SHCS + nyloc + washers | Bearing caps — 4 per bore, top+bottom cap bolted **through** each plate on the Ø58 BCD (grip 22 mm at both plates) |
| 2 | M25×1.5 shaft locknut (or KM5 + tab washer) | Shoulder bearing preload, above the upper cap |
| 4 | M5 × 75 SHCS + nyloc | Top plate → standoff → deck through-bolts (one per standoff, grip 64 mm — the Ø12 standoffs are clearance-bored Ø5.2, no threads) |
| 4 | M3 SHCS + nut | Distal elbow split-clamp pinch bolts (2 per clamp) |
| 2 | M5 set screw (cup point) | Shoulder D-bore axial retention onto the shaft flat |
| 2 | Ø8 shaft clip / printed clip | Elbow-pin top retention (bottom head is integral to the pin) |
| — | M5/M6 brass heat-set inserts | All printed bosses (cradle lock/fin/jack, carriage motor bosses) |
| — | assorted M4/M5/M6 washers | as needed |

[McMaster metric SHCS](https://www.mcmaster.com/products/screws/socket-head-screws~/system-of-measurement~metric/) · [set screws](https://www.mcmaster.com/products/set-screws/system-of-measurement~metric/)

## Quick shopping strategy

- **One order covers the drive:** all pulleys + belts from Beltingonline.
- **One order covers small bearings/pins/fasteners:** McMaster (688s, dowels,
  all screws, shaft collar) — fastest single-source.
- **Shoulder bearings + 25 h6 stock** are the two items worth spending a minute
  on: get a **matched 7005 DB pair** (or accept the 6005 stand-in for the
  prototype), and enough 25 h6 bar to make both shafts.
- **Two custom parts** need a lathe: the **shoulder shaft** (flat) and the
  **TCP spindle** (hollow + flange). Everything else is off-the-shelf or a
  pilot-bore + keyway job.

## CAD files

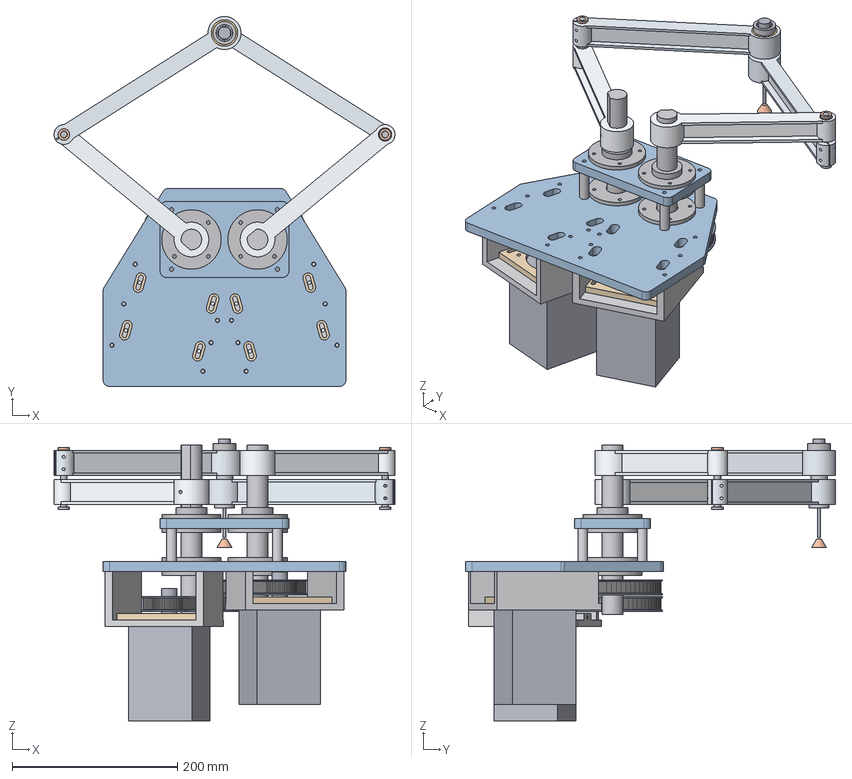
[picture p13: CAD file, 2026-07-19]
cad/step/dual_base_full.step
412.8 x 448.0 x 341.0 mm
bottom_deck
top_plate
plate_standoffs_40mm
shaft_L
brg7005_lo_L
brg7005_up_L
brgcap_lo_bot_L
brgcap_lo_top_L
brgcap_up_bot_L
brgcap_up_top_L
locknut_L
pulley72T_L
pulley24T_L
belt_450_5M_L
motor_carriage_L
motor_cradle_L
motor_A6M80_L
shaft_R
brg7005_lo_R
brg7005_up_R
brgcap_lo_bot_R
brgcap_lo_top_R
brgcap_up_bot_R
brgcap_up_top_R
locknut_R
pulley72T_R
pulley24T_R
belt_450_5M_R
motor_carriage_R
motor_cradle_R
motor_A6M80_R
proximal_L_planeA
proximal_R_planeB
distal_L_planeB
distal_R_planeA
elbow_pin_L_75mm
elbow_pin_clip_L
elbow_pin_R_75mm
elbow_pin_clip_R
brg6804_tcp_lower
brg6804_tcp_upper
tcp_spindle_O20xO16
tcp_collar
air_cyl_ISO6432_O10
vacuum_cup

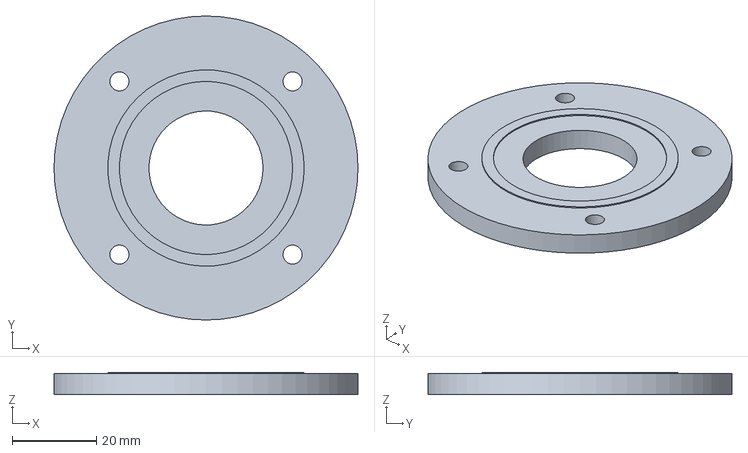
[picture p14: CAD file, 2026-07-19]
cad/step/bearing_cap.step
72.0 x 72.0 x 5.30 mm

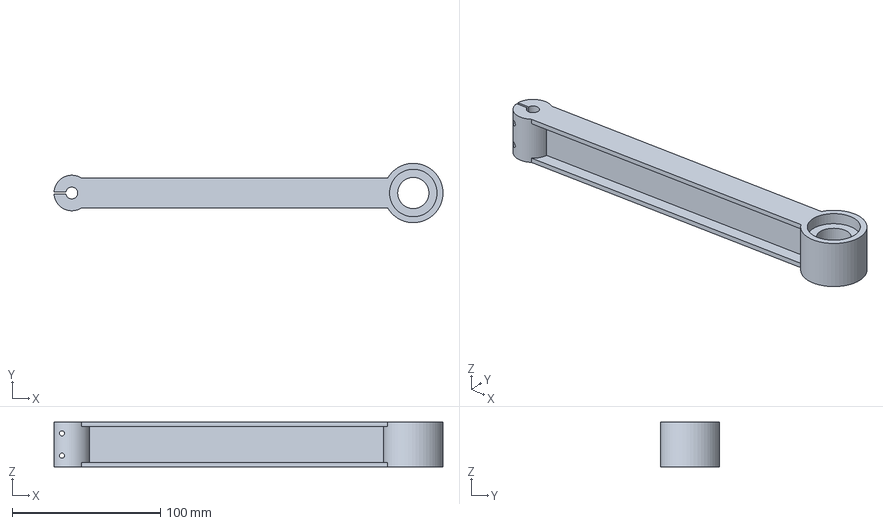
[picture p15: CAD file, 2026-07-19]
cad/step/distal_arm.step
262.0 x 40.0 x 30.0 mm

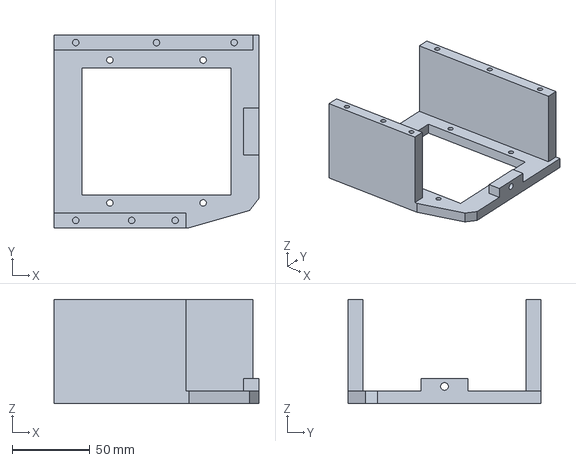
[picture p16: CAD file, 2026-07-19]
cad/step/motor_cradle_L.step
132.0 x 124.0 x 67.0 mm

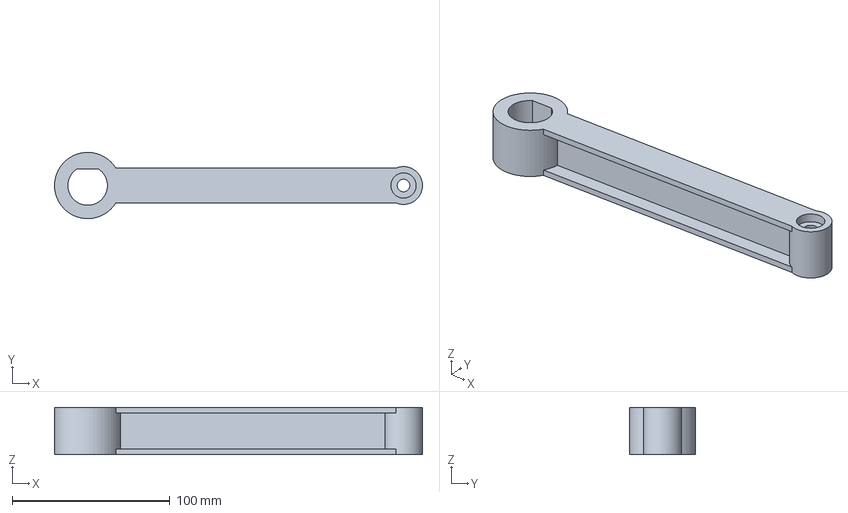
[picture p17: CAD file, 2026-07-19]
cad/step/proximal_arm.step
233.0 x 42.0 x 30.0 mm

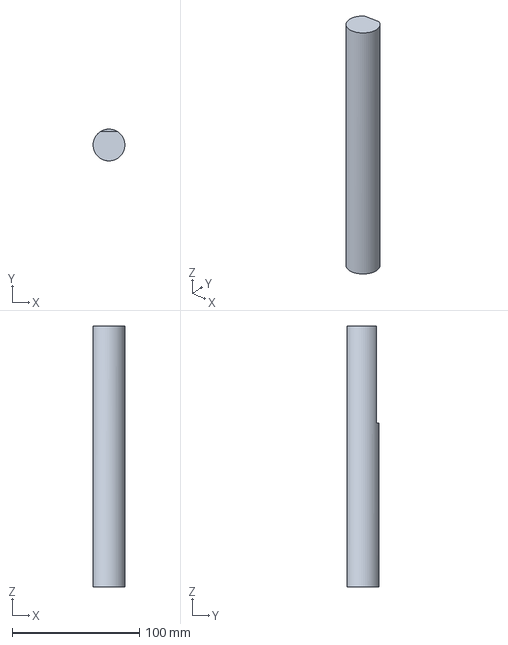
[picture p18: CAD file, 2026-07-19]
cad/step/shoulder_shaft.step
25.0 x 25.0 x 205.0 mm

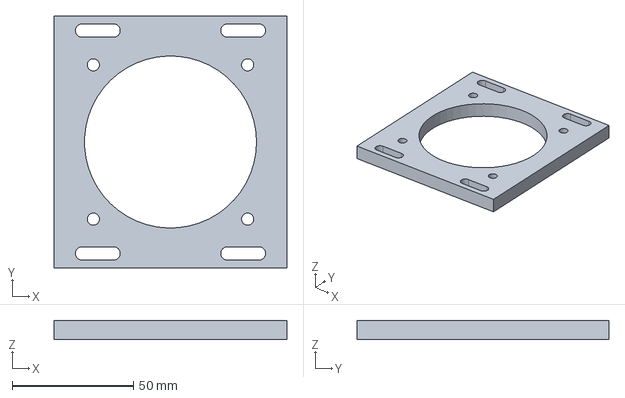
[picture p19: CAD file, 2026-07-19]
cad/step/motor_carriage.step
96.0 x 104.0 x 8.00 mm

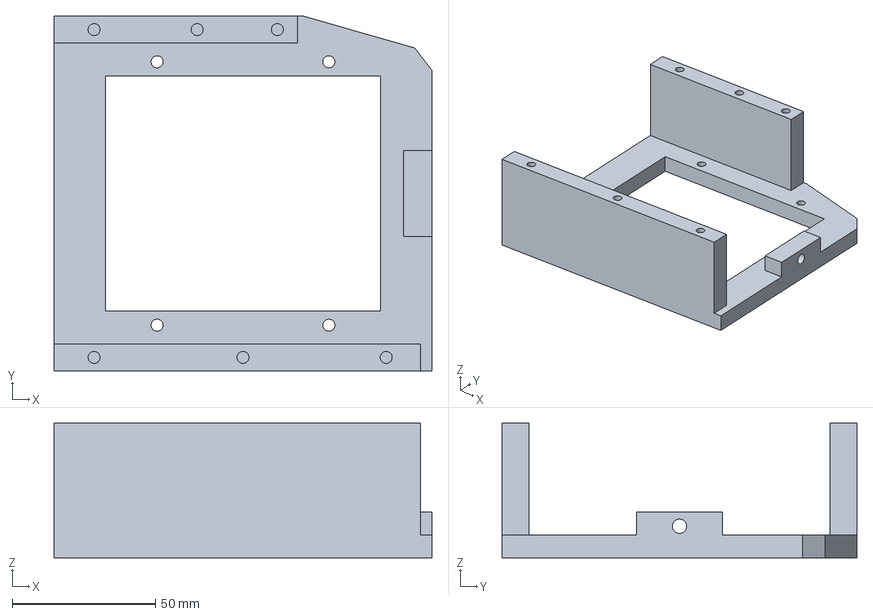
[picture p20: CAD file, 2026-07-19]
cad/step/motor_cradle_R.step
132.0 x 124.0 x 47.0 mm

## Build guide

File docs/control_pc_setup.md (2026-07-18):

# Control PC setup — Debian + PREEMPT_RT for the EtherCAT master

The reference/commissioning machine for the `pysoem` EtherCAT master. This is the
OS-and-platform half of bring-up; the fieldbus/drive half lives in
[`ethercat_bringup.md`](ethercat_bringup.md).

## Reference machine (validated)

| | |
|---|---|
| CPU | Intel **i7-9700K** — 8 cores / 8 threads, **no hyperthreading** |
| RAM | 16 GB (ample; vision + pysoem + HMI don't approach it) |
| OS | **Debian 13 (Trixie)**, 13.6, **XFCE on X11** |
| Kernel | `6.12.94+deb13-rt-amd64` — mainline **PREEMPT_RT** (`linux-image-rt-amd64`) |
| EtherCAT NIC | Intel **I219-V**, PCI `00:1f.6`, driver `e1000e`, pinned to iface **`ecat0`** |
| LAN / dev | onboard **WiFi** (EtherCAT and IP traffic stay on separate interfaces) |

The **no-HT** part is a real advantage: every core is standalone, so an isolated
RT core has no SMT sibling contending for execution units — nothing to disable,
cleaner isolation than an HT part.

Why this NIC split: EtherCAT is raw L2 (no IP). The Intel port carries **only**
the fieldbus; all IP traffic (apt, git, SSH, browser) rides WiFi. A single Intel
I219-V on `e1000e` drives both A6 servos fine. An add-in **Intel i210** PCIe card
is optional — add it only if a soak test says you want the "known-good" fieldbus
NIC; then EtherCAT moves to the i210 and the I219-V becomes the wired LAN.

## 1. RT kernel

```
sudo apt install linux-image-rt-amd64      # mainline-RT 6.12 on Trixie
# reboot into it, then confirm:
uname -r                                   # ...-rt-amd64
uname -v                                   # contains PREEMPT_RT
```

## 2. NIC — dedicate the Intel port to EtherCAT

Find the interface and confirm the driver. **Don't trust a predicted name** — the
kernel may use the onboard-index form (`eno2`) or the PCI-path form
(`enp0s31f6`), and it can flip across BIOS/kernel updates. Ask the tools:

```
lspci | grep -i ethernet                   # Intel I219-V at 00:1f.6
ip -br link                                # the real name (here it was eno2)
sudo .venv/bin/python -c "import pysoem; [print(a.name) for a in pysoem.find_adapters()]"
ethtool -i eno2                            # driver: e1000e, bus-info 0000:00:1f.6
```

**Pin it to a stable name** so `ethercat_ifname` can never drift. A systemd
`.link` file renames the port by MAC to `ecat0` for good:

```
cat /sys/class/net/eno2/address            # the port's MAC, e.g. 04:92:26:bd:5f:fe
sudo tee /etc/systemd/network/10-ecat.link >/dev/null <<'EOF'
[Match]
MACAddress=04:92:26:bd:5f:fe

[Link]
Name=ecat0
EOF
sudo update-initramfs -u
sudo reboot
# after reboot:
ip -br link                                # now: ecat0 ...
ethtool -i ecat0                           # driver: e1000e, 00:1f.6
```

`ecat0` is the `ifname` for `PysoemMaster` and the value for the Drives tab
`ethercat_ifname` field. It self-documents the port's job and survives renaming.
Bring it **up with no IP** (EtherCAT doesn't use IP):

```
sudo ip link set ecat0 up
```

No `dhclient`/static IP on this interface. Get WiFi associated and internet
working **before** dedicating the Intel port, or you'll lose apt/git on the box.
Disable WiFi power-save so the dev link doesn't hiccup on long sessions:

```
sudo iw dev <wlan> set power_save off
```

## 3. Core isolation + power tuning

Reserve cores **6 and 7** for the RT thread (one for the pysoem cyclic thread,
one spare); cores 0–5 run the OS, XFCE, IDE, HMI, and OpenCV vision.

Edit `/etc/default/grub`, append to `GRUB_CMDLINE_LINUX_DEFAULT`:

```
isolcpus=6,7 nohz_full=6,7 rcu_nocbs=6,7 intel_idle.max_cstate=1 processor.max_cstate=1
```

```
sudo update-grub && sudo reboot
cat /proc/cmdline                          # verify the flags took
```

Pin the CPU governor to performance (belt-and-suspenders with the BIOS):

```
sudo apt install linux-cpupower
sudo cpupower frequency-set -g performance
```

**BIOS settings** (K-series board exposes them all). These are the biggest lever
for the latency *tail* — kernel flags can't substitute, because the spikes come
from firmware the OS can't see:

- Disable **C-states** (or cap at C1) — deep-sleep wakeup is the classic tail spike.
- Disable **Turbo Boost** — its frequency transitions add jitter; determinism
  beats a few % peak clock here.
- Disable **SpeedStep / EIST** and set a fixed core frequency.
- Leave hyperthreading alone — the 9700K has none.

> **Measured on the reference machine** (isolated-core soak, stepping the BIOS):
> **Turbo on + C-states auto → ~84 µs**; **Turbo off + C-states off → ~47 µs**;
> **+ SpeedStep off → ~32 µs**. Each setting tightened the tail — it was
> firmware, exactly what these fix. Do the full BIOS pass; don't chase it in
> software.

## 4. Validate with cyclictest

```
sudo apt install rt-tests
```

**Baseline (all cores, loaded):**

```
sudo cyclictest -m -S -p 90 -i 200 -d 0 -D 30s
```

**RT-core soak (pin to isolated core 6, run long, under load):**

```
sudo cyclictest -m -p 90 -i 200 -d 0 -a 6 -t 1 -D 30m
```

> Do **not** combine `-S` (SMP mode) with `-a`/`-t` — `-S` forces one thread per
> CPU and *ignores* the affinity flags ("ignored due to smp mode"). Drop `-S` to
> pin a single thread to one core.

Load cores 0–5 *while it runs* — that's the realistic worst case:

```
stress-ng --cpu 6 --io 2 --timeout 30m       # or run the vision stack + a build
```

(Heavy `--vm` memory load is pessimistic: it contends on the shared memory
controller/L3, which isolation does **not** cover, so it overstates the real
vision workload. `--cpu` load or the actual vision stack is the honest test.)

If you want to confirm whether a residual spike is firmware, `hwlatdetect
--duration=5m` measures SMI/hardware latency directly — what cyclictest attributes
but can't fix.

**Acceptance:** worst-case **Max** must sit well under the CSP cycle time
(`cycle_dt_s` = **2 ms** by default). Comfortable = Max under ~100 µs.

**Reference machine result:** ~28–53 µs unisolated (30 s windows) → **84 µs**
once soaked with Turbo/C-states still on → **47 µs** after Turbo + C-states off →
**32 µs** after SpeedStep off too, on isolated core 6. That final **~1.6% of a
2 ms cycle** is the sign-off. A longer soak always finds a higher Max than a short
one, so judge on the long isolated run under load, not a 30 s window. With this
much headroom the platform is not the limiting factor; the cycle could be
shortened (1 ms / 500 µs) if ever needed.

## 5. pysoem

```
pip install pysoem                         # in the project venv
```

Keep the whole Python stack (pysoem, PySide6, OpenCV, PyYAML) in a **venv** so an
`apt` upgrade never disturbs the robot's interpreter.

pysoem opens a **raw L2 socket** and the RT thread needs scheduling privilege, so
the master needs two capabilities:

- **`CAP_NET_RAW`** — to open the EtherCAT socket on `ecat0`.
- **`CAP_SYS_NICE`** — so `SCHED_FIFO` + `mlockall` take (`set_realtime()` logs a
  warning if they don't).

Quickest for the bench is to run under sudo with the venv's interpreter
(`sudo .venv/bin/python …`) — plain `sudo python` uses system Python and won't
find pysoem. To run the HMI as your normal user without sudo, grant the caps to a
**copied** venv interpreter (`python -m venv --copies .venv`, then
`sudo setcap cap_net_raw,cap_sys_nice+eip .venv/bin/python3`) so the caps scope to
the venv, not the shared system interpreter.

Empty-bus sanity check (returns 0 slaves, no exception = the NIC/socket are good):

```
sudo ip link set ecat0 up
sudo .venv/bin/python -c "import pysoem; m=pysoem.Master(); m.open('ecat0'); print(m.config_init()); m.close()"
```

---

Continue with the fieldbus/drive checklist in
[`ethercat_bringup.md`](ethercat_bringup.md) (§2 drive parameters onward).

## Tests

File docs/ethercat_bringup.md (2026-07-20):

# EtherCAT bring-up — StepperOnline A6-EC + PC master

> **The real-hardware master is IgH EtherLab, not pysoem.** The AS715N is
> **DC-SYNC0-only**, and pysoem cannot generate a SYNC0 the drive detects (it
> faults `Er74.1` "No sync signal"). The IgH master does — **verified on the
> bench**: the drive holds OP with DC, `err=0x0000`, encoder live. Production runs
> on a small C RT daemon (`igh/ec_master_daemon`, using IgH's `libethercat`) that
> owns the DC loop and exposes the process data over shared memory, with
> `IgHMaster` (`src/bung_cover_robot/ethercat/igh_master.py`) as the Python side
> behind the same `EtherCatMaster` interface. **See [`../igh/README.md`](../igh/README.md)**
> for install/build/run. `PysoemMaster` is kept for reference / non-DC drives but
> is not used for this hardware.

The PC is the motion controller. It streams Cyclic-Synchronous-Position (CSP)
setpoints to the A6-EC servo drives over a single EtherCAT segment. The sections
below (PDO map, homing, safety, first-motion) apply regardless of master; the
pysoem-specific mechanics are historical.

> Everything above this layer (CiA 402 sequencing, the Cartesian CSP trajectory
> planner, the `EtherCatRobotDriver`, the whole pick/place cycle) is already
> tested in software against `SimulatedEtherCatMaster` — run it with
> `python -m bung_cover_robot.gui --sim-ec`.

## 1. Control PC / OS

Full platform build (RT kernel, NIC, core isolation, cyclictest acceptance) is in
[`control_pc_setup.md`](control_pc_setup.md). In short:

- Linux with a **PREEMPT_RT** kernel (`uname -v` shows `PREEMPT_RT`). Without it,
  CSP following error will grow under load.
- A **dedicated Intel NIC** for EtherCAT, wired point-to-point to drive 1's IN
  port, drive 1 OUT → drive 2 IN. The interface name (reference machine: the
  I219-V `e1000e` port, MAC-pinned to `ecat0` via a systemd `.link` file — see
  [`control_pc_setup.md`](control_pc_setup.md) §2) is the `ifname` for
  `PysoemMaster` and the Drives tab `ethercat_ifname` field. Keep IP traffic on a
  separate interface (WiFi).
- Isolate CPU cores for the RT thread (reference machine, 8-core no-HT:
  `isolcpus=6,7 nohz_full=6,7 rcu_nocbs=6,7`), then pin the process; grant
  `CAP_SYS_NICE` (or run the master as root) so `SCHED_FIFO` + `mlockall` take
  (`set_realtime()` logs a warning if they don't).
- `pip install pysoem` on the control PC (in the project venv).

## 2. Drive parameters (set once per drive, in the A6 tool or over SDO)

| Setting | Value | Why |
|---|---|---|
| EtherCAT station alias | 1 (left), 2 (right) | stable slave identity |
| Control mode | CSP (Cyclic Sync Position, mode 8) | streamed position |
| Electronic gear / encoder | 17-bit = 131072 counts/rev | feeds deg↔counts |
| Homing method (0x6098) | switch + index per your fixtures | see §4 |
| Following-error window | tight enough to trip on a stall | safety |
| STO | wired to the safety relay (see §5) | E-stop |

**Update `config/robot_config.yaml`** so the software deg↔counts matches the
drive: set the drivetrain to the servo (`pulses_per_rev: 131072`, belt ratio as
built). The planner and driver share `pulses_per_degree`, so this must be right
or moves land at the wrong angle.

### Object dictionary is the source of truth — not the panel Cxx.NN

`esi/STEPPERONLINE_A6_Servo_V0.02.xml` is the drive's EtherCAT Slave Info: the
real object dictionary (indices, subindices, ranges, sizes). The panel's
`Cxx.NN` numbering does **not** track the SDO subindex in group `0x2000` — the
subindex is the entry's *position* in the ESI object, not `NN+1`. Always read
the address from the ESI. The Drives-tab tuning table is preloaded from it:

| Tuning object | CoE | Default | Range | Notes |
|---|---|---|---|---|
| Load inertia ratio | `0x2000:07` | 100 | 0–12000 % | set first |
| Auto-tuning mode | `0x2000:05` | 1 | 0=Manual/1=Standard/2=Positioning | 0 to hand-tune gains |
| Stiffness level | `0x2000:06` | 12 | 1–31 | main dial in Standard mode |
| 1st position loop gain | `0x2001:01` | 400 | 0–20000 (0.1 rad/s) | |
| 1st speed loop gain | `0x2001:02` | 250 | 1–20000 (0.1 Hz) | raise before position gain |
| 1st speed loop integral time | `0x2001:03` | 3184 | 1–51200 (0.01 ms) | lower = stronger integral |
| 1st torque ref filter | `0x2001:04` | 200 | 5–16000 Hz (cutoff) | lower = more damping |

All U16, modifiable during operation, effective immediately. In Standard mode
(auto-tune = 1) the loop gains are derived from the stiffness level, so stiffness
is the primary knob; set auto-tune = 0 to write the loop gains directly.

## 3. PDO map (0x1C12 / 0x1C13)

**Verified on the bench** (`scripts/ec_inspect.py`): the ANCTL AS715N (the
StepperOnline A6-EC) ships a fixed native map that `master.py` now matches
exactly — little-endian, packed:

```
RxPDO 0x1701 (PC → drive, 12 B):
  Controlword 0x6040 (U16) | TargetPosition 0x607A (S32)
  | TouchProbe 0x60B8 (U16) | DigitalOutputs 0x60FE:1 (U32)
TxPDO 0x1B01 (drive → PC, 28 B):
  ErrorCode 0x603F (U16) | Statusword 0x6041 (U16) | PositionActual 0x6064 (S32)
  | TorqueActual 0x6077 (S16) | FollowingError 0x60F4 (S32)
  | TouchProbeStatus 0x60B9 (U16) | TouchProbe1 0x60BA (S32)
  | TouchProbe2 0x60BC (S32) | DigitalInputs 0x60FD (U32)
```

Notes:

- **Mode of operation (0x6060) is not cyclic** in this map, so `_configure_slave()`
  writes CSP (8) once over SDO. The drive already powers up in CSP.
- The map hands us **following error** and **digital inputs (0x60FD)** for free —
  the Drives page shows real switch states and following error — plus a **digital
  output word (0x60FE:1)** that drives the **pick head**: `EtherCatRobotDriver`
  asserts bit 0 for the vacuum solenoid and bit 1 for the air-cylinder plunger on
  drive 0 (the `vacuum_do_bit` / `plunger_do_bit` / `tooling_drive` constructor
  args repoint this to a dedicated EtherCAT I/O slice later). The daemon rewrites
  the whole DO word every DC cycle, so a set bit stays asserted until cleared.
- The touch-probe words are carried but unused (packed/ignored as 0).
- If a future drive ships a *different* default PDO, re-verify with
  `scripts/ec_inspect.py` and adjust `_RX_FMT`/`_TX_FMT`.
  `tests/test_ethercat_master.py` pins the pack/unpack layout.

## 4. Homing

This machine homes to **hard mechanical stops — no home switches.** Procedure:
drive each axis to its hard stop (jog, or push by hand while disabled), then
press **Set Home** on the Drives tab. `set_home()` captures the current encoder
counts as the datum and declares that pose to be the configured `home_angles`
(from `robot_config.yaml`). All subsequent Cartesian moves are referenced to it.

> The configured `home_angles` **must match the physical hard-stop pose**, or
> every Cartesian move is offset by the difference. Set `home_angles` to the
> actual shoulder angles at the hard stops.

(`home()` still implements CiA 402 homing mode 6 for a switch-equipped drive —
puts both drives in Homing mode, runs the drive's homing method to the switch —
but it is not used on this machine.)

**Encoder type matters (drive param C00.07).** Set it to match the motor:

- **Single-turn absolute** (current bench motors): the datum survives a *disable*
  (drive stays powered), so no re-home on a mid-session enable. But a full
  **power-off** loses the multi-turn count — with the 3:1 reduction the drive
  then only knows the shoulder angle modulo 120°, so **re-home after every power
  cycle**.
- **Multi-turn absolute** (battery-backed): the revolution count survives
  power-off too, so the datum is truly persistent — home once, ever.
  **One-time step:** after setting C00.07=4 and fitting the encoder battery,
  *clear the drive's multi-turn data* (absolute-encoder reset), power-cycle,
  then Set Home. Skipping this leaves the multi-turn counter one (or more)
  revolutions off, so a move ends an exact multiple of **131072 counts**
  (one encoder rev) short and never settles. The move's failure message now
  recognises that whole-turn signature and says to clear the datum rather
  than (wrongly) blaming servo tuning.

  **Use LINEAR mode, not rotary.** A multi-turn absolute encoder reports
  position one of two ways, and the choice is decisive here:
  - *Rotary / rollover* — the reported position (`0x6064`) **wraps within one
    revolution**. Fine for an endlessly-spinning axis (turntable/spindle),
    but wrong for this arm: the shoulder's work area is **−20°…200° = 220° =
    1.83 motor revs** (3:1 belt), so a normal move *crosses* the single-turn
    boundary. When it does, the reported position snaps by exactly ∓131072
    while the drive itself does **not** fault (its internal loop uses the full
    multi-turn value) — so a move ends 131072 counts short with no alarm.
    Clearing the datum does not help; the wrap is structural. Because the
    work area legitimately spans more than one rev, software *cannot* safely
    fold this out (two real poses can sit exactly one rev apart), so it must
    be fixed at the drive.
  - *Linear (bounded)* — the position accumulates **continuously across
    single-turn boundaries** over the whole multi-turn range (±32767 revs).
    This is the correct choice: the shoulder oscillates inside a ~1.83-rev
    arc and accumulates zero net revolutions, so it never approaches the
    range ends. Pick plain **linear**, *not* "linear infinite" (that mode is
    for an axis that rotates one direction without end and buys a finite arm
    nothing). After switching, clear the multi-turn data once more (so the
    continuous count starts centered), power-cycle, and Set Home.
  - *Confirm it took:* jog one shoulder across the work area and watch the
    drive's raw actual counts climb smoothly **past 131072 into the low
    hundred-thousands with no snap back toward 0**.

Either way the software requires a home on each program launch (`is_referenced`
starts `False`), so start-up is safe; the difference is only whether a routine
power cycle forces an operator re-home. If C00.07 is left on **incremental**, the
drive ignores the absolute datum entirely and homes from wherever it powered up.

### 4d. Drive drops to SWITCH ON DISABLED with no fault

If a drive falls out of Operation Enabled *without* a fault, the power-stage
enable chain blipped — the drive was told (or forced) to drop torque, it did
not trip. Usual culprits, most likely first:

1. **STO / E-stop chain chatter** — a marginal contact or connector on the
   safety relay/contactor path opens for a few ms (vibration at higher
   speeds makes this worse). The refusal message now flags this when the
   statusword's voltage bit is down.
2. **24 V logic dip** — shared supply sagging under load.
3. **Drive sync-loss reaction** configured as "servo off" (warning class)
   rather than a latching fault.

The "cannot move: drives are disabled" error now names the drive, its decoded
CiA 402 state, and the raw statusword/error code. The bench demo auto
re-enables ONCE per job after an unexpected disable (never after a fault) and
tags the run result with how many times it had to — repeated auto re-enables
mean fix the chain, not the software.

**Prove or rule out the cable/EMI (the #1 cause) — built into the Drives
tab.** The status table's **"Link errors (CRC)"** row shows each drive's ESC
error counters live (the daemon reads registers 0x0300..0x0313 ~1 Hz and
publishes them over shared memory — no CLI, no sudo, no second process).
Press **Zero CRC ctrs**, run a speed trial, and watch the row: it stays
"0 (clean)" on a good link and goes red with a breakdown (`75  rx37 inv37
lost1`) on a bad one. Requires daemon ABI 4 — after pulling, rebuild once:
`make -C igh ETHERLAB=/opt/etherlab` (the app refuses an old daemon with a
clear message). `scripts/ec_crc.py` remains as a standalone fallback. RX-error / invalid-frame climbing on a port = the cable
segment feeding that port; lost-link = an intermittent connector; forwarded
errors = the fault is upstream (nearer the PC). A real drive fault never moves
these — anything that climbs under load is physical-layer, so fix the cabling
(shielded S/FTP, away from the motor power leads) before anything else.

### 4c. "Move did not settle" — tolerance and settle window

The end-of-move check is governed by two **Motion parameters** (Drives tab,
persisted, applied on Connect and on Apply):

- `position_tol_counts` — default **500** (~0.46° at the joint with the 17-bit
  encoder × 3:1; ≈1.5–2 mm at the TCP). The old default of 5 counts (0.005°)
  was only achievable in the simulator.
- `settle_timeout_s` — default **2.0 s**. The servo's integrator needs real
  time to pull in the last fraction of a degree after the CSP stream ends; a
  longer window often lets you run a *tighter* tolerance.

If moves still time out, the error now reports the per-drive shortfall in
counts and degrees. A persistent shortfall of hundreds of counts is a tuning
problem (raise stiffness, or auto-tune=0 and raise position loop gain / lower
the speed-loop integral time) or belt wind-up — the tolerance only decides
when to complain about it.

### 4b. Spurious "drives are faulted" aborts (fixed by debounce)

A demo/move can only be refused for a fault if the CiA 402 fault bit survives
**three consecutive fresh PDO cycles** (`_confirmed_fault()`), and a CSP stream
only aborts on **two consecutive** faulted samples. A real A6 fault LATCHES
until reset, so the debounce can never hide one — but a single torn
shared-memory read racing the RT daemon (or a one-cycle bus hiccup) no longer
kills a run with a phantom "cannot move: drives are faulted". When a fault IS
real, the error now carries the actual per-drive statusword and error code
(e.g. `drive 0: sw=0x0218 err=0x7500`) instead of just a drive number; ignored
transients are logged as warnings so they stay visible.

### 4a. Sample pick & place (vision bypass)

The Drives tab has a **Simulate pick && place** button (in the jog box) to
exercise the arm and pick head before vision calibration exists. It needs the
drives **enabled** and **Set Home** done, then runs a canned cycle: pick from a
**fixed supply nest** (same spot every time), drop into a **six-hole battery**
laid out just like the real thing — six covers in a straight line at **35 mm
pitch** — that is placed at a random position/tilt in the reachable envelope each
pass (so a range of poses gets exercised while the battery geometry stays
realistic). Every point is workspace-validated, and the vacuum/cylinder actuate
at each end just like a real pick. Tick **loop** to keep it running (re-placing
the battery each pass) until you press **Stop demo**. The **cycles/min** readout
shows a rolling average of completed placements per minute (trailing 60 s).

This is `run_demo_cycle` + `demo_pick_and_place_targets` (both in
`app/cycle_manager.py`), the same `DirectJobRunner` the vision cycle uses — it
just supplies fixed targets instead of camera detections.

**Speed.** The demo travels at the **jog speed** set in the jog box (a gentle
default), *not* the full `speed_mm_s` motion limit — a big point-to-point move at
the tuned maximum can outrun an under-tuned servo and trip the drive's
**excessive-position-deviation** alarm (StepperOnline A6 **Er.47** / CiA 402
error `0x8611`, the ESI's "Excessive position deviation threshold"). If you still
see Er.47, lower the jog speed further, drop `accel_mm_s2`, or raise the drive's
deviation threshold / retune the loop gains — the arm is being commanded faster
than it can follow.

### Tuning assistant (Drives tab → "Tuning…")

The **root cause** of speed-proportional Er.47 is that we stream **position
only** (CSP) and, out of the box, the A6's **speed feedforward is off**
(`C01.13 Speed feedforward selection = 0`, ESI object `0x2001:20`). Without it a
position loop lags in direct proportion to velocity, so following error climbs
with speed until it trips. The assistant fixes and measures this without the
guesswork:

1. **Load inertia (C00.06)** — estimated from the arm *geometry* (`robot/inertia.py`),
   **not** the drive's native inertia auto-tune (`F30.10`). That routine free-spins
   one axis several turns; on the assembled 5-bar the shoulders are coupled through
   the linkage, so it would fight the mechanism and exceed the joint window. Enter
   your motor's rotor inertia (Jm) for a trustworthy ratio.
2. **Speed feedforward** — sets `C01.13 = 1` (internal reference: FF derived from
   the position-command slope) and `C01.14` to the chosen gain (`0x2001:21`,
   0.1 % units; start 50 %, climb toward 100 %). Written to both drives and saved.
3. **Characterize** — runs a *validated* out-and-back TCP move (never a free
   spin) and reports the **peak following error** in counts, degrees, and as a
   percentage of the `0x6065` fault window. Raise FF/stiffness and re-run to watch
   the peak fall; only growth past the window trips Er.47.

Peak following error is captured inside the CSP streaming loop (read-only on the
real master, exact in the simulator), so the number reflects the whole move, not
a slow GUI sample.

**Start-of-move chirp / accel-phase spike.** A hard trapezoidal profile steps
acceleration on instantly (infinite jerk), which impulsively excites a mechanical
resonance — an audible chirp plus a following-error spike at the *start* of a
move. The planner is **jerk-limited (S-curve)**: `jerk_mm_s3` (motion parameter,
default 80000 mm/s³) eases acceleration in over ~`accel/jerk` seconds, removing
the impulse with almost no loss of cruise speed. Set it to 0 for the old hard
trapezoid; lower it for a gentler/quieter start at the cost of a little move
time. Torque feedforward (`C01.16`/`C01.17`) complements it for the accel phase.

**Velocity feedforward streaming (0x60B1) — the chirp-free FF.** With speed-FF
source = internal reference (`C01.13 = 1`), the drive derives its feedforward by
*differentiating the position command we stream*. In CSP that command is a
per-cycle staircase, so the derivative is spiky — it turns into an audible chirp
and a following-error ripple (worst as speed rises; jerk limiting doesn't help
because it's the command granularity, not the ramp). The fix is to feed the
drive OUR trajectory's velocity directly: the daemon maps `0x60B1` (velocity
offset) into the flexible RxPDO `0x1600` and streams the per-cycle velocity
(counts/s) alongside the position, and the drive is set to speed-FF source =
Communication (`C01.13 = 5`) so it uses it. Clean feedforward, no differentiation
→ tight tracking *and* no chirp, independent of load inertia.

To enable it:
1. Rebuild the daemon (ABI bumped to 5): `make -C igh ETHERLAB=/opt/etherlab`,
   then `sudo pkill ec_master_daemon` and reconnect.
2. Set `C01.13 = 5` (`speed_ff_source`) on both drives.
3. `velocity_ff_scale` (motion parameter, default 1.0) trims the streamed value
   for the drive's velocity-offset units — if FF over/under-compensates, adjust
   it until the characterize FE minimises. 0 disables streaming.

## 5. Safety (hardware, not software)

- **E-stop → hardwired torque removal, independent of the PC.** Two cases:
  - *Drive has STO:* E-stop → safety relay → both drives' STO. STO removes torque
    directly. Preferred.
  - *Drive has no STO* (the bench AS715N): E-stop → safety relay → **contactor
    that drops the drives' motor/bus power**. Slower than STO (the axis brakes /
    coasts as the bus collapses) but still a real stop that works even if the PC
    or drive firmware hangs. **Do not enable or jog a drive until this exists and
    is tested**, and keep the motor mechanically secured on the bench.
  Either way, this hardwired stop is primary; the software `stop()` (hold
  position) is secondary.
- Home/limit switches → the drives' digital inputs (used by the homing method and
  as hard travel limits).
- Vacuum + air cylinder → drive 0's DO word (0x60FE:1) today (vacuum = bit 0,
  plunger = bit 1); repointable to a small EtherCAT I/O slice later. The
  pick/place cycle (`DirectJobRunner`) sequences them: travel → plunge → vacuum
  ON → dwell → lift → travel → plunge → vacuum OFF → dwell → lift, with the dwells
  set by `PickSequence`. Wire the vacuum confirm switch back to a DI so the cycle
  can verify a cover is held.

## 5b. Single-axis bench bring-up

For bench work on **one drive** before the robot is assembled, set **Drives on
bus = 1** in the Drives-tab Connection box (persisted as `ethercat_num_drives`).
The master then expects a single slave, the Drives page shows that axis live
(state, encoder counts, following error, I/O, parameter table) and marks the
absent second panel "not on bus". **Connecting produces no torque** — the drive
stays in `switch_on_disabled` until you deliberately enable it, so viewing is
safe with no power-stage interlock in place. Enabling/jogging is *not* safe until
the stop interlock below exists.

## 5c. The AS715N is DC-SYNC0-only (the Er741 story)

Read the drive's own sync config with `scripts/ec_inspect.py`: the AS715N's sync
managers (`0x1C32`/`0x1C33:04`) advertise **only DC-SYNC0** — no free-run, no
SM-sync. **DC is therefore mandatory.** If the drive enters OP without a programmed
SYNC0 pulse, it faults with a **synchronization-signal error — `Er741`**. (Trying
to run free-run, or picking Profile Position to dodge sync, does *not* help: the
sync-manager requirement is below the CiA 402 mode.)

So `open()` (with `use_dc=True`, the default) **enables DC and programs SYNC0** at
the cycle time:

```
m.config_dc()
for s in slaves:
    s.dc_sync(True, cycle_dt_s * 1e9)   # SYNC0 period in ns
```

The drive's ESC then generates SYNC0 from its own DC-synchronized clock, so the RT
loop only has to keep frames flowing each cycle (which it does). On the PREEMPT_RT
control PC (isolated core, ~32 µs jitter) a 2 ms cycle holds this comfortably.

Mode of operation is independent of this: bench single-axis still uses Profile
Position (mode 1) for simple jogging, the 2-drive robot uses CSP (8) — **both over
DC-SYNC0**.

**Fault codes (from the A6-EC troubleshooting chapter):**

| Fault | Name | 0x603F |
|---|---|---|
| **Er74.0** | EtherCAT synchronization cycle setting error | 0x6320 |
| **Er74.1** | **No sync signal** | **0x8700** |
| Er74.2 | Chip synchronization process uncompleted in OP | 0x8700 |
| ErC1.0 | Excessive EtherCAT synchronization period error | 0x8700 |

**`Er74.1` (0x8700) = "No sync signal"** — the drive sees **zero SYNC0 pulses**.
This is a signal-*generation* fault, not a timing one: if `slave.dc_sync(...)`
were producing SYNC0 but mistimed, you'd get `Er74.0`/`ErC1.0` instead. Getting
`Er74.1` means the master isn't generating a SYNC0 the drive detects — check that
`pysoem`'s DC activation (`config_dc()` + `slave.dc_sync()`) actually fires SYNC0
(pysoem version, DC reference-clock selection), not the SYNC0 cycle/shift values.

## 6. First-motion checklist (do this once, slowly)

1. `--sim-ec` full cycle passes in software. ✅ (already tested)
2. Master reaches OP: all slaves to OP_STATE, `receive_processdata` WKC == #slaves.
3. Arm one drive to Operation Enabled; confirm the statusword decodes as expected.
4. **Jog test at low speed** (`TrajectoryLimits(speed_mm_s=20)`): a short move,
   watch following error stay small.
5. Home to the switches; verify `read_angles()` matches the taught home pose.
6. Run a single pick/place with vision bypass and a low speed cap before full rate.
7. Only then raise `TrajectoryLimits` speed/accel toward the inertia-matched limits.

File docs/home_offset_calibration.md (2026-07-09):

# Home-offset calibration (`HOME_OFFSET_L` / `HOME_OFFSET_R`)

How to measure and set the two home-offset constants so the PLC reports the
**true** shoulder angles after homing. Do this once per machine at
commissioning (and again only if you move a home switch or change the homing
approach). The app does the math — you build a simple jig, seat the tool on it,
and click **Compute**. Backed up/restored with the **PLC tab → Commissioning
constants** panel (see `plc_setup.md`).

---

## 1. What the offset is, and why it exists

The ClearLink zeroes each motor's position **at the home-switch (prox) trip
point**, not at a meaningful shoulder angle. Right after homing,
`Motor0/1_CommandedPosn = 0` even though the arm sits at some real angle. The
PLC converts commanded steps to a published angle with:

```
ActualLeftDeg  = (Motor0_CommandedPosn + HOME_OFFSET_L) / STEPS_PER_DEG
ActualRightDeg = (Motor1_CommandedPosn + HOME_OFFSET_R) / STEPS_PER_DEG
```

* **Motor0 = left** shoulder, **Motor1 = right** shoulder.
* `STEPS_PER_DEG = 26.66667` (3200 pulses/rev × 3:1 / 360).

`HOME_OFFSET` is therefore **the true shoulder angle at the trip point, in
steps**. If the switch tripped exactly at the design home pose
(L 140.5406° / R 39.4594°) the offsets would be the shipped nominals
**3748 / 1052**. In practice the switch is a few tenths off, so you measure the
real value.

> **You don't measure the home angle directly — you derive it.** Homing tells
> you nothing about the absolute angle, and you never find out. What the
> ClearLink *does* give you after homing is a **running count of steps commanded
> away from the trip point** (`CommandedPosn`, zeroed at home). So: jog to a
> point whose true angle you know from its coordinate; the count is how far the
> arm moved to get there. A known endpoint minus the counted move gives the
> start:
>
> ```
> angle_at_home = θ_jig − CommandedPosn / STEPS_PER_DEG
> HOME_OFFSET   = angle_at_home × STEPS_PER_DEG
>               = θ_jig × STEPS_PER_DEG − CommandedPosn
> ```
>
> Like pacing off the distance from a labeled mark: you don't need to know where
> you started, only the known endpoint and the steps you counted getting there.
> The jig supplies that one absolute reference — without it you'd have only
> relative motion and no way to anchor it.

> **Open-loop steppers — no encoder.** The EM806 drives are open-loop; the
> ClearLink's `CommandedPosn` is the **commanded step count** from the home
> datum, not an encoder reading. That's exactly what we want here: right after
> homing there are no lost steps, so the commanded count *is* the arm's position
> relative to the trip point. Jog gently to the jig (don't stall) so no steps
> are dropped between home and the measurement.

> **Why not a digital level?** This is a horizontal-plane SCARA — the arms sweep
> in a plane parallel to the floor. A gravity inclinometer reads 0° everywhere
> in that plane, so it can't measure the in-plane shoulder angle. The offset is
> calibrated from a **known TCP position** instead.

---

## 2. Before you start

Calibrate the offset **last**, after these are done — an offset measured on a
drifting or mis-scaled axis is worthless:

1. **Homing is repeatable.** `HOME_VEL_0/1` sign drives *toward* the prox, the
   back-off/re-approach is tuned, and re-homing several times lands the same
   trip point (watch `M0/M1 CommandedPosn` return to 0 consistently).
2. **`STEPS_PER_DEG` is verified.** Command a 90° shoulder jog and measure the
   real sweep; fix step wiring / microstepping until it matches 26.66667.

---

## 3. Build the jig (establish one known point)

You need **one point whose robot-frame (X, Y) you know**. The robot frame origin
is the **midpoint between the two shoulder pivots**; +X runs along the line
joining them (toward the right pivot), +Y is perpendicular, into the work area.
The two pivots sit at **(−40, 0)** and **(+40, 0)** mm (80 mm base spacing).

Calibration jig, top view

The easy, accurate point is **on the centerline (X = 0)** — the locus
equidistant from both pivots. Build it like this:

1. **Mark the two shoulder-pivot centers** (the motor output-shaft axes). These
   define the frame; measure them carefully.
2. **Mount a vertical dowel pin** on the base plate, out in the work zone
   (~250 mm from the pivot line is ideal — that's in the stiff part of the
   envelope).
3. **Slide/adjust the pin until it is equidistant from both pivots.** Measure
   pin-center → left-pivot and pin-center → right-pivot with a caliper or tape;
   make them equal. Call that equal distance **d**. The pin is now at **X = 0**,
   and:

   ```
   Y = sqrt(d² − 40²)          # 40 mm = half the 80 mm base spacing
   ```

   (e.g. d = 253.2 mm → Y = √(253.2² − 40²) = 250.0 mm.) No perpendicular
   measurement needed — one equal-distance reading gives you the coordinate.
4. **Fit a self-centering tool tip.** Swap the vacuum cup for a pointed probe or
   a bushing that mates the dowel (cone-into-hole or pin-into-bushing). It
   removes the guesswork of "is it seated" and repeats to a few thousandths.

> **Cross-check (recommended):** add a second pin at a different Y on the same
> centerline. Calibrating from each should give offsets that agree within a step
> or two. A big disagreement means the trip point isn't repeatable (§2.1) or
> `STEPS_PER_DEG` is off (§2.2).

---

## 4. Run the calibration (in the app)

No calculator, no command line — the program reads the counts and solves it.

1. **Home** the robot (Robot Test → Home). Confirm `Has Homed`; both
   `CommandedPosn` read ~0.
2. **Seat the tool** on the jig pin (jog there gently in small steps).
3. Open **PLC tab → Commissioning constants → "Calibrate HOME_OFFSET from a
   known point."**
4. Enter the jig's **X** and **Y** (e.g. `0` and your computed `Y`).
5. Click **Compute from PLC.** The app reads both `Motor*_CommandedPosn`, solves
   `HOME_OFFSET = round(θ·STEPS_PER_DEG − CommandedPosn)` per axis, and shows the
   angles, the counts, and the resulting offsets.
6. Click **Apply to table** to drop the two values into the `HOME_OFFSET_L/R`
   rows, then **Push to PLC…** to write them live.

---

## 5. Verify

Re-home, jog the tool back onto the jig, and confirm the Diagnostics tab now
reads `ActualLeftDeg ≈ θL`, `ActualRightDeg ≈ θR` for that point. If you built a
second pin, check it tracks there too.

---

## 6. Back it up (disaster recovery)

Once verified, click **Read from PLC (snapshot)** in the same panel. It saves
the whole set-by-hand set — including your calibrated offsets — to
`config/plc_constants.yaml`. If the controller is ever reloaded or cleared,
**Push to PLC** restores it in one shot. (Studio 5000 does not restore these on
a program download; the snapshot file is your backup, and it is git-ignored
because the values are specific to your physical machine.)

---

## 7. When to re-calibrate

Re-run this procedure if you:

* move or replace a home switch / prox sensor,
* change the homing approach direction or `HOME_VEL` sign,
* rebuild an arm (new links, re-set the elbow assembly), or
* change `STEPS_PER_DEG` (microstepping or belt ratio).

A stale offset shows up as the robot reaching poses consistently rotated from
the commanded angle, or the two arms disagreeing about where the TCP is.

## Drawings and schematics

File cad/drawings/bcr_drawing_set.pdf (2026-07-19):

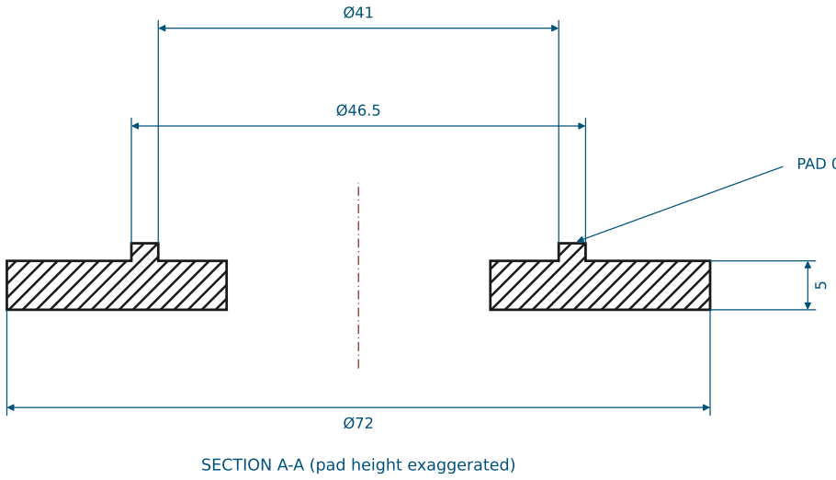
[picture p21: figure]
SECTION A-A (pad height exaggerated)

### 5-BAR BUNG-COVER ROBOT — BASE HARDWARE

TITLE: BEARING RETAINER CAP | DWG NO: BCR-01 REV A
MATERIAL: PA12 MJF / 6061-T6 | QTY: 8
SCALE 1.5:1 UNITS mm THIRD ANGLE | SHEET 1 OF 6 2026-07-19

# SHEET 1: BEARING RETAINER CAP (BRG-CAP)

GENERAL TOLERANCES UNLESS NOTED: X ±0.5 X.X ±0.2 HOLES +0.2/-0 ANGLES ±0.5° BREAK ALL EDGES 0.3
DUAL MATERIAL CALLOUTS: select ONE per order — printed parts take brass heat-set inserts at every thread callout; 6061 parts are tapped.
1. One cap above AND one below each 7005 bearing bore; the pair bolts together THROUGH the plate with 4x M4x30 SHCS + nyloc (plate holes 4.5 on the same BCD; grip 22 = 5+12+5 at BOTH plates).
2. Both plates are 12 THK = the 7005 race width, so the race sits FLUSH with the plate faces and the cap disc seats FLAT on the plate.
3. The 0.3-proud pad (41-46.5) lands on the bearing OUTER race only - torquing the bolts gives a small defined clamp crush on the race. No spigot: the cap must NOT stand off the plate.
4. Build one cap pad-UP and one pad-DOWN per bore (same part, flipped).
5. OD is 72 so the bolt holes keep a full 1.5d rim (edge distance 4.75).

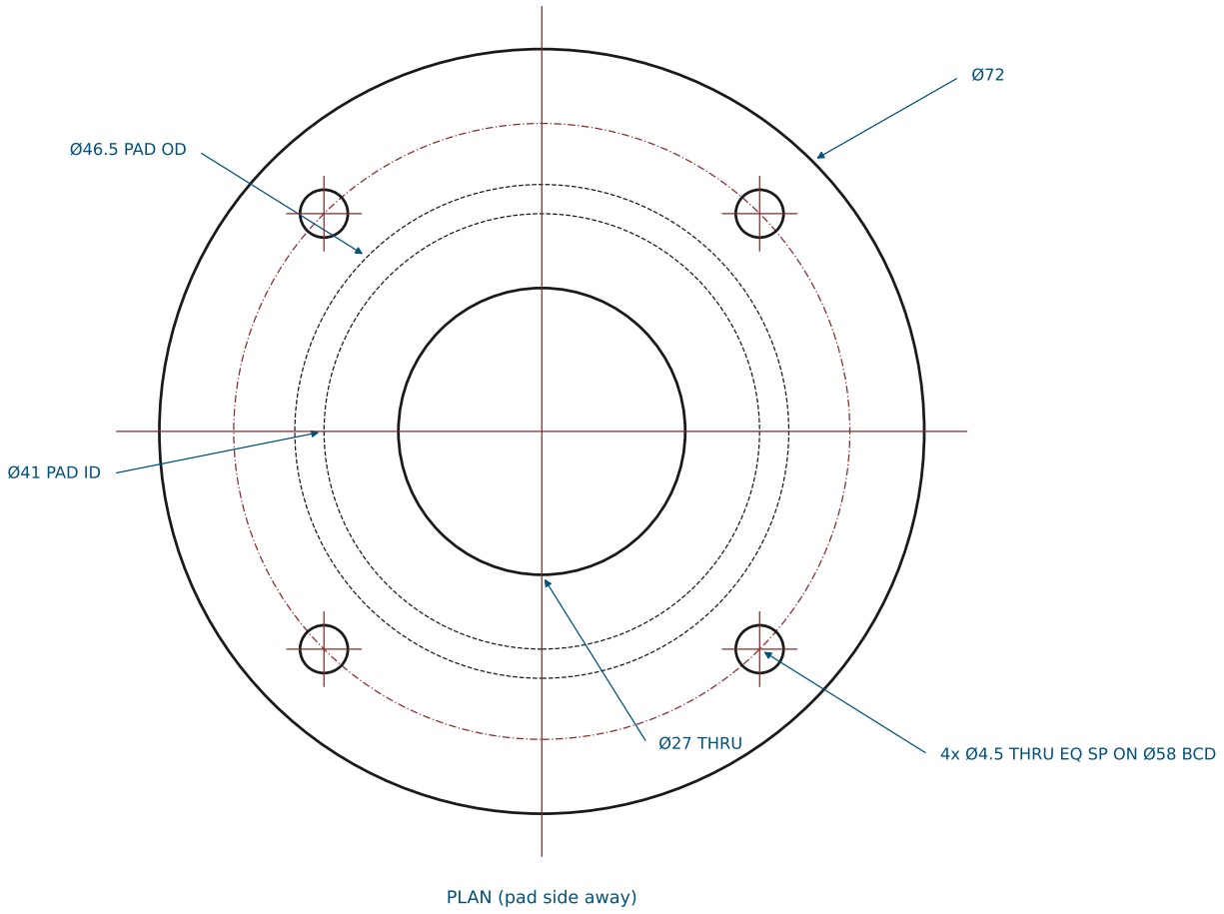
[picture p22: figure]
4x Ø4.5 THRU EQ SP ON Ø58 BCD Ø27 THRU; Ø46.5 PAD OD; Ø41 PAD ID; PLAN (pad side away)

PAD 0.3 PROUD - presses OUTER race only

# SHEET 2: SLIDING MOTOR CARRIAGE (CARRIAGE)

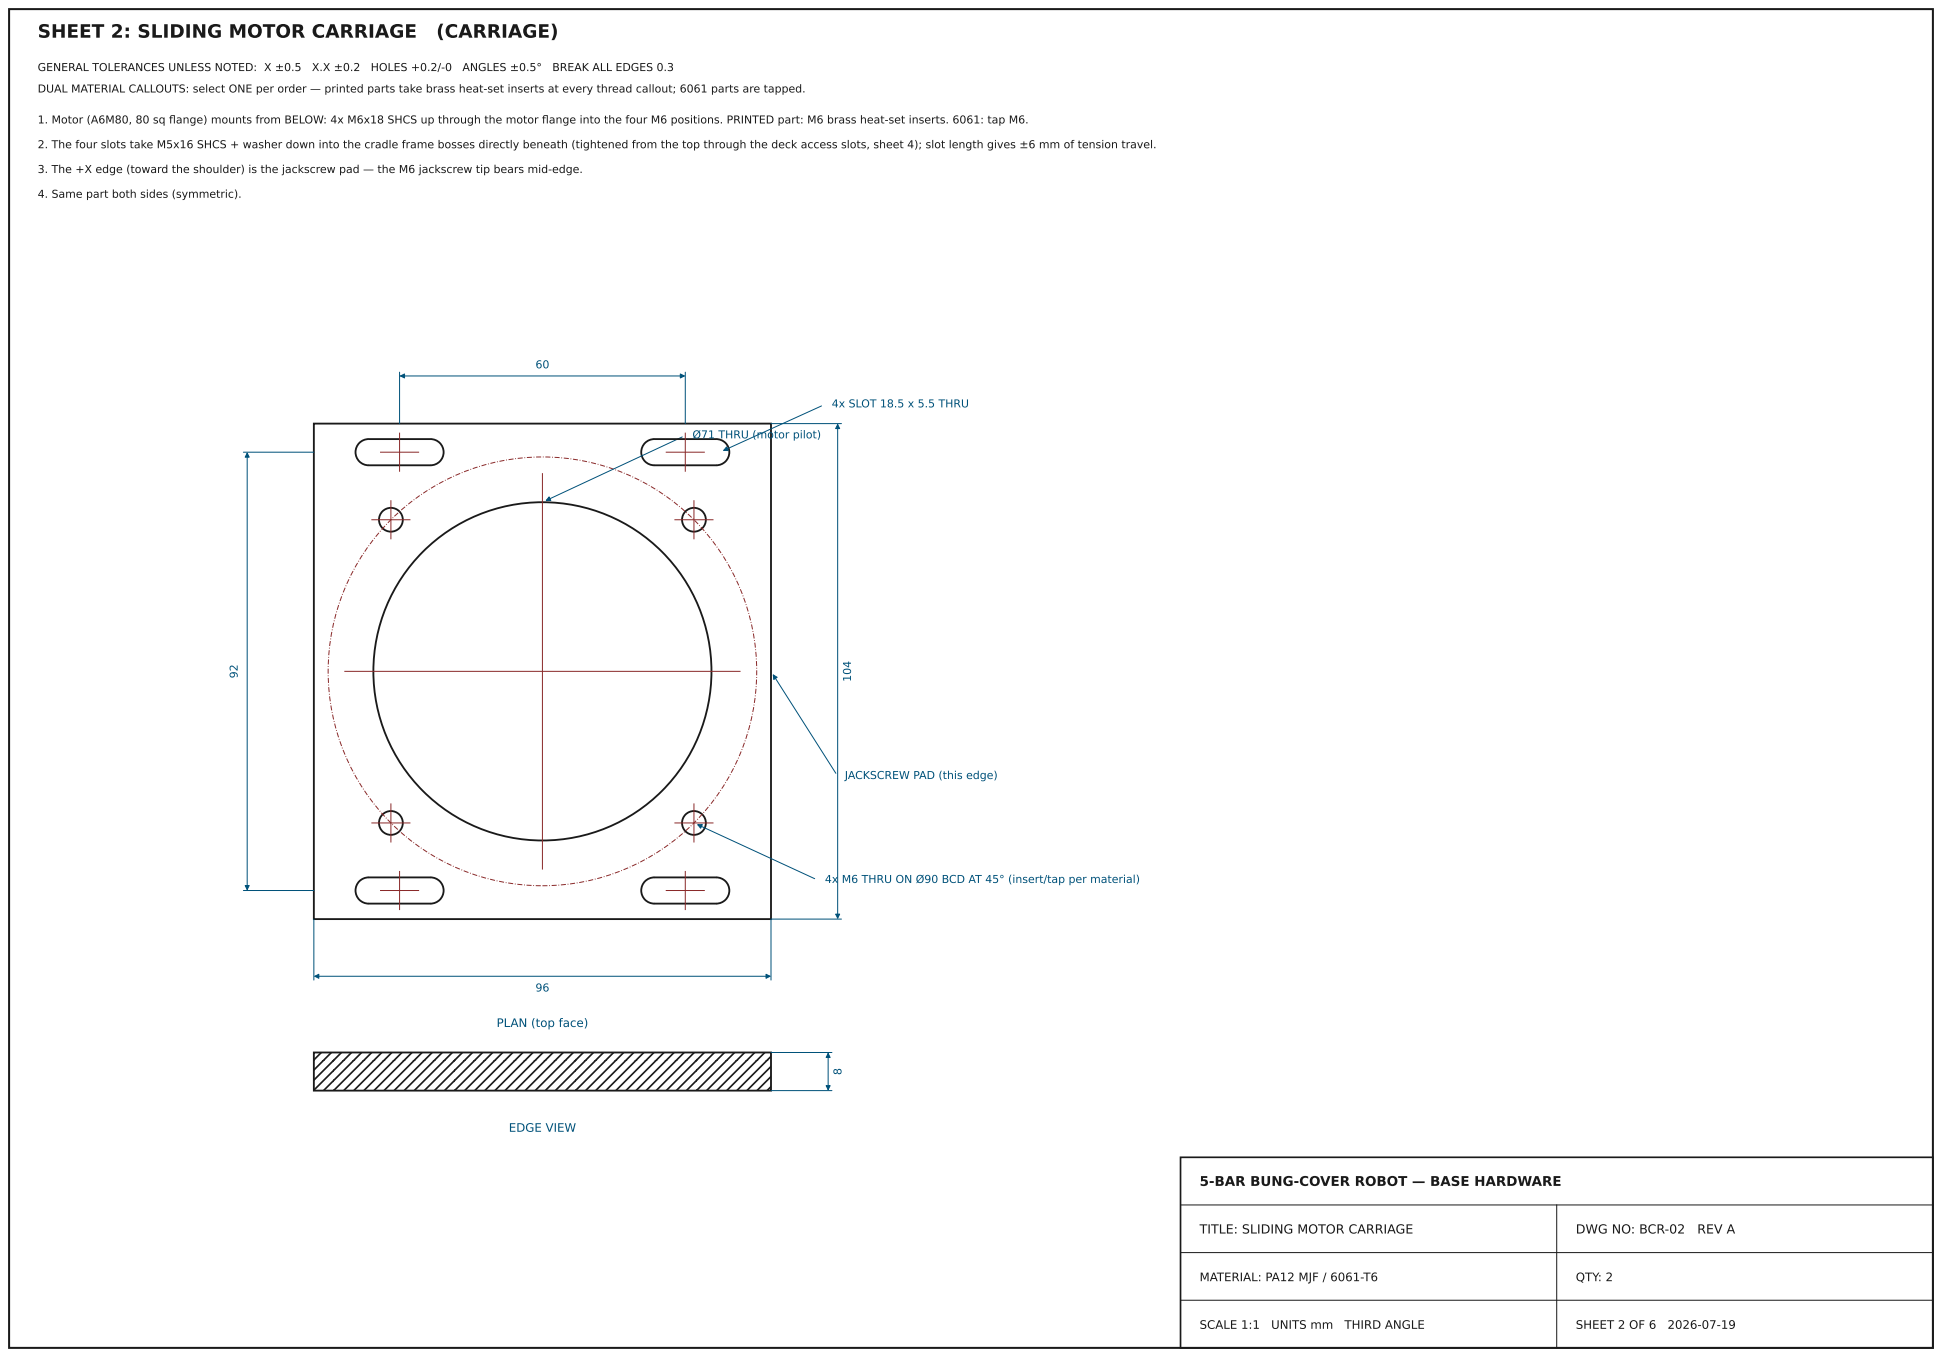
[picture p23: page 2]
TITLE: SLIDING MOTOR CARRIAGE; DWG NO: BCR-02 REV A; MATERIAL: PA12 MJF / 6061-T6; QTY: 2; SCALE 1:1 UNITS mm THIRD ANGLE; SHEET 2 OF 6 2026-07-19; 4x SLOT 18.5 x 5.5 THRU; EDGE VIEW

1. Motor (A6M80, 80 sq flange) mounts from BELOW: 4x M6x18 SHCS up through the motor flange into the four M6 positions. PRINTED part: M6 brass heat-set inserts. 6061: tap M6.

2. The four slots take M5x16 SHCS + washer down into the cradle frame bosses directly beneath (tightened from the top through the deck access slots, sheet 4); slot length gives ±6 mm of tension travel.

3. The +X edge (toward the shoulder) is the jackscrew pad — the M6 jackscrew tip bears mid-edge.

4. Same part both sides (symmetric).

Ø71 THRU (motor pilot)

JACKSCREW PAD (this edge)

4x M6 THRU ON Ø90 BCD AT 45° (insert/tap per material)

PLAN (top face)

5-BAR BUNG-COVER ROBOT — BASE HARDWARE

### 5-BAR BUNG-COVER ROBOT — BASE HARDWARE

TITLE: SLIDER CRADLE (LH SHOWN, RH = MIRROR) | DWG NO: BCR-03 REV A
MATERIAL: PA12 MJF / PETG-CF (print flat, frame down) | QTY: 1 + 1 (mirror)
SCALE 1:2 / 1:1 UNITS mm THIRD ANGLE | SHEET 3 OF 6 2026-07-19

# SHEET 3: SLIDER CRADLE (LH SHOWN, RH = MIRROR) (CRADLE-L / CRADLE-R)

1. ONE printed part per motor = window frame + two shear fins + jack block. The RH part is the exact MIRROR of the LH drawn here; fin/wall heights differ per the table (belt planes stagger).
2. Fins are SOLID full-depth walls (9.5 thick, guide face to frame edge). They bolt UP into the deck underside: 3x M5 full-depth heat-set per fin, M5x20 SHCS from the deck top (deck holes 5.2 THRU).
3. The four M5 positions in the frame border take the carriage lock bolts — fit heat-set inserts.
4. M6 heat-set (or tapped) jackscrew boss in the block; jam nut on the screw against the block face.
5. The chamfered corner keeps the two cradles clear of the machine centreline — do not 'square it up'.
6. FIN WALLS: solid, inner (guide) faces at b = ±52.5, 9.5 thick out to the frame edge. Outboard wall spans a = -66..+62, inboard a = -66..+19. Inner faces guide the carriage edges (0.5 nominal).
7. Install the belt around both pulleys BEFORE bolting the deck down (the fins close the corridor). 9.5

M6 JACKSCREW BOSS

132

124

WINDOW 96

x 82

60

92

4x M5 HEAT-SET (lock bolts) 3x M5 HEAT-SET ON 57.25 LINE

3x M5 HEAT-SET | CORNER CUTS (21.0,-62) -> (60,-50.8) -> (66,-43) [clears the opposite 72T pulley - do not square up]

PLAN — LH PART (frame top; fins rise toward viewer)

DATUM: origin at frame centre. +a = toward the shoulder (jack-block end), +b = toward the OUTBOARD fin. All holes in the HOLE TABLE.

10

30

DECK UNDERSIDE z52

H (table)

8

M6 AXIS +3 ABOVE FRAME TOP

8 BLOCK

ELEVATION (outboard fin)
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

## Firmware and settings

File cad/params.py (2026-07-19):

"""Single source of truth for the base-hardware layout (pure math, no CAD deps).

Every dimension shared by the solid model (generate.py) and the machine-shop
drawing set (drawings.py) lives HERE, so the model and the paper drawings can
never drift apart. ``check_layout()`` re-derives every clearance — bolt edge
distances, belt-corridor offsets, deck containment, centreline gaps — and
raises AssertionError before either output can be produced from a colliding
layout.

Coordinate frames
-----------------
world  : robot XY. Shoulder shafts at (+-HX, 0), motors behind at (+-MXx, MXy).
         Z up through the deck stack.
local  : per-motor 'belt frame'. a = along the belt axis, positive from the
         motor TOWARD its shoulder; b = lateral, positive OUTBOARD (away from
         the machine centreline).  Right side: world = M + a*U + b*V; the left
         side mirrors x.

Tensioner architecture (this revision)
--------------------------------------
Each motor bolts (4x M6, from below through the flange) to a sliding CARRIAGE
plate.  The carriage rides on a fixed CRADLE: a window frame directly under
the carriage whose two full-length SHEAR FINS rise to the deck underside and
bolt to it (3x M5 per fin through a top flange).  The fins guide the carriage
edges and carry the belt-tension shear into the deck.  Four M5 LOCK BOLTS pass
down through +-6 mm slots in the carriage into the cradle frame right below —
the slots clamp onto real tapped material, not open air.  A JACKSCREW (M6)
through an integral block on the cradle's shoulder-side border pushes the
carriage away from the shoulder to tension; belt pull keeps it in compression.
Everything stays inside the deck outline (asserted) and the whole stack still
prints on a 300x300 bed.
"""

from __future__ import annotations

import math

# --------------------------------------------------------------------- drive
BELT_PITCH = 5.0                       # HTD-5M
T_MOT, T_DRV = 24, 72                  # 3:1 (24T keeps hub wall over the keyway)
PD_MOT = T_MOT * BELT_PITCH / math.pi  # 38.197
PD_DRV = T_DRV * BELT_PITCH / math.pi  # 114.592
BELT_LEN = 450.0                       # stock 450-5M-15 (90T)
_wrap = math.pi * (PD_MOT + PD_DRV) / 2
_k = (PD_DRV - PD_MOT) ** 2 / 4
C = ((BELT_LEN - _wrap) + math.sqrt((BELT_LEN - _wrap) ** 2 - 8 * _k)) / 4

# Motor-shaft pulley bore + keyway (DIN 6885: O19 shaft -> 6 mm key, hub keyseat
# 2.8 mm above the bore). Wall left between keyseat and pulley body OD:
MOTOR_BORE = 19.0
KEY_HUB_DEPTH = 2.8
PULLEY_BODY_R = PD_MOT / 2 - 0.7       # solid body radius under the teeth
PULLEY_KEY_WALL = PULLEY_BODY_R - (MOTOR_BORE / 2 + KEY_HUB_DEPTH)

# ------------------------------------------------------------------- layout
HX = 40.0                              # shoulder half-spacing (base_spacing/2)
SPLAY = math.radians(16.0)             # motor splay out from -Y
SIN_S, COS_S = math.sin(SPLAY), math.cos(SPLAY)
MXx = HX + C * SIN_S                   # motor axis x (right side)
MXy = -C * COS_S                       # motor axis y (behind the shoulders)
# right-side local basis (left mirrors world x)
U = (-SIN_S, COS_S)                    # a: motor -> shoulder
V = (COS_S, SIN_S)                     # b: outboard

ZL, ZR = 5.0, 25.0                     # belt plane bottoms (staggered)
PW = 15.0                              # pulley / belt face width
ARM_H = 30.0

# ------------------------------------------------------- carriage (sliding)
MP_T = 8.0                             # carriage plate thickness
MPL_TOP, MPR_TOP = 1.0, 21.0           # carriage top faces (belt stagger)
TENSION = 6.0                          # jackscrew travel along the belt (+-)
CAR_L, CAR_W = 96.0, 104.0             # carriage: length (a) x width (b)
PILOT_D = 71.0                         # motor pilot bore (O70 spigot + 1)
MOTOR_BCD = 90.0                       # motor flange bolts, M6 at 45 deg
LOCK_A = 30.0                          # lock-bolt line, +- along a
LOCK_B = 46.0                          # lock-bolt line, +- along b (1.5 mm
                                       # insert wall to the window edge)
SLOT_L = 2 * TENSION + 6.5             # 18.5 slot: full +-6 travel with margin
SLOT_W = 5.5                           # M5 clearance slot width
# Tool-access slots THROUGH THE DECK, projected over each lock bolt so the
# heads can be reached with an allen key from the top (they sit ~45 mm below
# the deck; there is no side access). Long axis = the travel direction.
ACC_W = 12.0                           # clears an M5 head (8.5) + 4 mm key wobble
ACC_L = 2 * TENSION + ACC_W            # 24: follows the bolt over +-6 travel

# --------------------------------------------------------- cradle (fixed)
FR_A = 66.0                            # frame half-length (a)
FR_B = 62.0                            # frame half-width (b)
FR_T = 8.0                             # frame plate thickness
WIN_A = 48.0                           # window half-length (motor + travel)
WIN_B = 41.0                           # window half-width (80 flange + 1)
# Fins are SOLID full-depth walls (no web-and-flange section): from the guide
# face at FIN_BI out to the frame edge at FIN_BO, frame bottom to the deck.
# Simpler print, stiffer, and the deck bolts get full-depth heat-sets.
FIN_BI = 52.5                          # fin wall inner face (guides carriage)
FIN_BO = 62.0                          # fin wall outer face = frame edge (9.5 solid)
FIN_A_OUT = 62.0                       # outboard fin wall ends (a)  [both +-]
FIN_A_INN = 19.0                       # inboard fin wall forward end (a) —
                                       # limited by the centreline clip at the
                                       # full 62 width (asserted)
FLG_B = 62.0                           # fin outer edge (= FIN_BO; kept for the
                                       # deck-containment corner points)
FIN_BOLT_B = 57.25                     # fin->deck M5 line (mid-wall)
FIN_BOLTS_OUT = (-52.0, 0.0, 50.0)     # a-positions, outboard fin
FIN_BOLTS_INN = (-52.0, -16.0, 12.0)   # a-positions, inboard fin
BLK_A0, BLK_A1 = 56.0, 66.0            # jack block along a (front border)
BLK_B = 15.0                           # jack block half-width
BLK_H = 8.0                            # jack block above frame top
JACK_Z_OFF = 3.0                       # screw axis above frame top
CL_MARGIN = 1.5                        # keep-out each side of centreline
# Second (deeper) corner cut at the inboard-front corner: the RIGHT frame's
# z-band (5..13) is coplanar with the LEFT 72T pulley flange + belt, and the
# straight centreline clip alone left that corner 0.44 mm INSIDE the opposite
# flange sweep. The cut runs from (CUT_A, on the clip line) to (FR_A, CUT_B),
# keeping every frame point clear of the opposite flange circle + belt strand
# (both asserted below).
CUT_A = 60.0
CUT_B = -43.0

# ------------------------------------------------- z stack (bottom-up, mm)
CAP_T = 5.0                            # bearing-cap thickness
BRG_W = 12.0                           # 7005 width (= deck thickness)
DECK_T = 12.0
DECK_Z0 = ZR + PW + 12.0               # deck bottom (52), clear of high belt
DECK_Z1 = DECK_Z0 + DECK_T             # 64
STANDOFF = 40.0
TOPP_Z0 = DECK_Z1 + STANDOFF           # 104
TOPP_T = 12.0                          # = 7005 width: race sits FLUSH with both
                                       # faces of each plate, caps seat flat
TOPP_Z1 = TOPP_Z0 + TOPP_T             # 116
LOCKNUT_T = 8.0
UCAP_TOP = TOPP_Z1 + CAP_T             # 119
LOCKNUT_Z = UCAP_TOP
ARM_GAP = 4.0
PLANE_A = LOCKNUT_Z + LOCKNUT_T + ARM_GAP + ARM_H / 2
PLANE_B = PLANE_A + 35.0
SHAFT_LEN = 205.0
A0, A1 = PLANE_A - ARM_H / 2, PLANE_A + ARM_H / 2
B0, B1 = PLANE_B - ARM_H / 2, PLANE_B + ARM_H / 2

# ------------------------------------------------------------ bearing caps
# The 7005 race (12 wide) sits FLUSH in its 12-thick plate; each cap is a flat
# disc that bolts down onto the plate face, with a 0.3 mm PROUD annular pad
# that lands on the outer race only — a defined clamp crush, instead of the
# old 2 mm register spigot that held the whole disc off the plate and clamped
# through cap flex.
CAP_OD = 72.0                          # was 62: bolt holes broke out of the OD
CAP_BCD = 58.0                         # 4x M4 through cap+plate+cap
CAP_BOLT_D = 4.5
CAP_PAD_OD = 46.5                      # pad presses the outer race only ...
CAP_PAD_ID = 41.0                      # ... clear of the inner race + cage
CAP_PAD_H = 0.3                        # proud of the disc face (clamp crush)
CAP_SHAFT_CLR = 27.0

# ------------------------------------------------------------------- plates
DECK_PTS = [(-72.0, 62.0), (72.0, 62.0), (147.0, -60.0), (147.0, -178.0),
            (-147.0, -178.0), (-147.0, -60.0)]
BED = 300.0                            # print bed (square)
STANDOFF_PTS = [(64.0, 36.0), (64.0, -36.0), (-64.0, 36.0), (-64.0, -36.0)]
TOPP_W, TOPP_H = 156.0, 92.0           # wide enough that the O72 caps at
                                       # +-40 stay fully on the plate

# TCP joint (unchanged)
SPINDLE_OD, SPINDLE_ID = 20.0, 16.2
TCP_BRG_OD, TCP_BRG_W = 32.0, 7.0
CYL_BARREL_OD = 15.0


# --------------------------------------------------------------- helpers
def belt_half(a: float) -> float:
    """Belt-corridor half-width at ``a`` mm from the motor (+2 mm margin)."""
    return PD_MOT / 2 + (a / C) * ((PD_DRV - PD_MOT) / 2) + 2.0


def clip_b(a: float) -> float:
    """Inboard limit: most-negative allowed b at ``a`` so the part stays
    CL_MARGIN clear of the machine centreline (right side)."""
    return -((MXx - CL_MARGIN) - SIN_S * a) / COS_S


def local_to_world(sgn: int, a: float, b: float):
    """(a, b) in the belt frame of side ``sgn`` (+1 right / -1 left) -> world.
    b is positive OUTBOARD on both sides."""
    x = MXx - SIN_S * a + COS_S * b
    y = MXy + COS_S * a + SIN_S * b
    return (sgn * x, y)


def frame_poly_local():
    """Cradle frame outline in (a, b). Two inboard-front cuts:
    1. the centreline clip (from (a1, -FR_B) along clip_b to (CUT_A, ...)),
       keeping the two cradles CL_MARGIN clear of the machine centreline;
    2. the corner cut to (FR_A, CUT_B), keeping the corner clear of the
       OPPOSITE side's 72T pulley flange and belt strand (they share this
       z-band; asserted in check_layout)."""
    a1 = (MXx - CL_MARGIN - COS_S * FR_B) / SIN_S
    return [(-FR_A, -FR_B), (a1, -FR_B), (CUT_A, clip_b(CUT_A)),
            (FR_A, CUT_B), (FR_A, FR_B), (-FR_A, FR_B)]


def deck_access_slots():
    """Tool-access slots through the deck, one over each carriage lock bolt:
    (id, world_x, world_y, angle_deg) with the long axis along the travel
    direction. ACC_L x ACC_W, THRU."""
    rows = []
    n = 1
    for sgn in (1, -1):
        ang = math.degrees(math.atan2(COS_S, -sgn * SIN_S))
        for sa in (LOCK_A, -LOCK_A):
            for sb in (LOCK_B, -LOCK_B):
                x, y = local_to_world(sgn, sa, sb)
                rows.append((f"A{n}", x, y, ang))
                n += 1
    return rows


def deck_hole_table():
    """Every deliberate hole in the deck: (id, x, y, dia, note)."""
    rows = []
    n = 1
    for sx in (HX, -HX):
        rows.append((f"B{n}", sx, 0.0, 47.0, "7005 bearing bore, thru")); n += 1
    n = 1
    for sx in (HX, -HX):
        for ang in (45, 135, 225, 315):
            bx = sx + CAP_BCD / 2 * math.cos(math.radians(ang))
            by = CAP_BCD / 2 * math.sin(math.radians(ang))
            rows.append((f"C{n}", bx, by, CAP_BOLT_D, "M4 cap bolt, thru")); n += 1
    n = 1
    for px, py in STANDOFF_PTS:
        rows.append((f"S{n}", px, py, 5.2, "M5 standoff bolt, thru")); n += 1
    n = 1
    for sgn in (1, -1):
        for a in FIN_BOLTS_OUT:
            x, y = local_to_world(sgn, a, FIN_BOLT_B)
            rows.append((f"F{n}", x, y, 5.2, "M5 fin bolt, thru")); n += 1
        for a in FIN_BOLTS_INN:
            x, y = local_to_world(sgn, a, -FIN_BOLT_B)
            rows.append((f"F{n}", x, y, 5.2, "M5 fin bolt, thru")); n += 1
    return rows


# ------------------------------------------------------------------ checks
def _dist_pt_seg(p, s0, s1):
    px, py = p; x0, y0 = s0; x1, y1 = s1
    dx, dy = x1 - x0, y1 - y0
    L2 = dx * dx + dy * dy
    t = 0.0 if L2 == 0 else max(0.0, min(1.0, ((px - x0) * dx + (py - y0) * dy) / L2))
    cx, cy = x0 + t * dx, y0 + t * dy
    return math.hypot(px - cx, py - cy)


def _inside_poly(p, poly):
    x, y = p
    inside = False
    for i in range(len(poly)):
        x0, y0 = poly[i]; x1, y1 = poly[(i + 1) % len(poly)]
        if (y0 > y) != (y1 > y) and x < x0 + (y - y0) * (x1 - x0) / (y1 - y0):
            inside = not inside
    return inside


def _deck_margin(p):
    d = min(_dist_pt_seg(p, DECK_PTS[i], DECK_PTS[(i + 1) % len(DECK_PTS)])
            for i in range(len(DECK_PTS)))
    return d if _inside_poly(p, DECK_PTS) else -d


def check_layout(verbose: bool = False) -> list:
    """Re-derive every clearance; raise AssertionError on any violation."""
    notes = []

    def ok(cond, margin, what):
        notes.append(f"{'ok ' if cond else 'FAIL'} {what}: {margin:+.2f} mm")
        assert cond, f"{what}: margin {margin:+.2f} mm"

    # -- drive / pulleys ------------------------------------------------
    ok(PULLEY_KEY_WALL >= 3.5, PULLEY_KEY_WALL - 3.5,
       "motor-pulley hub wall over keyway (>=3.5)")
    m = (ZR - 1.5) - (ZL + PW + 1.5)
    ok(m >= 2.0, m - 2.0, "staggered driven pulleys pass in z")
    m = (DECK_Z0 - 3.0) - (ZR + PW + 1.5)
    ok(m >= 0.0, m, "high driven pulley clears deck underside")
    m = (DECK_Z0 - CAP_T) - (ZR + PW + 1.5)
    ok(m >= 3.0, m - 3.0, "deck bottom cap clears the pulley flange")
    rot_half = 40.0 * (COS_S + SIN_S)          # 80-frame rotated by SPLAY
    m = 2 * (MXx - rot_half)
    ok(m >= 6.0, m - 6.0, "motor bodies clear each other at centreline")

    # -- bearing caps -----------------------------------------------------
    edge = CAP_OD / 2 - (CAP_BCD / 2 + CAP_BOLT_D / 2)
    ok(edge >= 3.0, edge - 3.0, "cap bolt hole edge distance (>=3)")
    ok(CAP_OD / 2 - CAP_BCD / 2 >= 1.5 * CAP_BOLT_D,
       CAP_OD / 2 - CAP_BCD / 2 - 1.5 * CAP_BOLT_D, "cap bolt 1.5d edge rule")
    m = 2 * HX - CAP_OD
    ok(m >= 4.0, m - 4.0, "adjacent bearing caps clear each other")
    m = CAP_BCD / 2 - CAP_BOLT_D / 2 - 23.5
    ok(m >= 2.5, m - 2.5, "cap bolt hole to O47 plate bore wall")
    so = math.hypot(STANDOFF_PTS[0][0] - HX, STANDOFF_PTS[0][1])
    m = so - CAP_OD / 2 - 6.0
    ok(m >= 1.0, m - 1.0, "cap clears standoff boss")
    m = TOPP_W / 2 - (HX + CAP_OD / 2)
    ok(m >= 1.0, m - 1.0, "top plate fully covers the O72 caps")
    m = CAP_BCD / 2 - CAP_BOLT_D / 2 - CAP_PAD_OD / 2
    ok(m >= 2.0, m - 2.0, "cap bolt hole to pressing pad")
    # races must sit flush so the flat caps seat on the plate faces
    ok(abs(DECK_T - BRG_W) < 0.01, 0.0, "deck thickness = 7005 race width")
    ok(abs(TOPP_T - BRG_W) < 0.01, 0.0, "top plate thickness = 7005 race width")
    m = 47.0 - CAP_PAD_OD
    ok(m >= 0.3, m - 0.3, "pressing pad stays inside the bore edge")

    # -- carriage ---------------------------------------------------------
    m = CAR_W / 2 - (LOCK_B + SLOT_W / 2)
    ok(m >= 3.0, m - 3.0, "carriage slot to carriage edge")
    m = LOCK_B - 3.5 - WIN_B
    ok(m >= 1.4, m - 1.4, "cradle lock-bolt boss to window edge")
    m = (LOCK_B - 5.0) - belt_half(LOCK_A + SLOT_L / 2)
    ok(m >= 3.0, m - 3.0, "lock bolt head clear of belt corridor")
    m = FIN_BI - (LOCK_B + 5.0)
    ok(m >= 1.45, m - 1.45, "lock bolt head clear of fin wall")
    m = SLOT_L / 2 - (TENSION + 2.5)
    ok(m >= 0.5, m - 0.5, "slot end clear of the bolt shank at full travel")
    m = WIN_B - 40.0
    ok(m >= 1.0, m - 1.0, "window clears motor flange laterally")
    m = WIN_A - (40.0 + TENSION)
    ok(m >= 1.5, m - 1.5, "window clears motor flange at travel extremes")
    m = FIN_BI - CAR_W / 2
    ok(0.3 <= m <= 1.0, m - 0.3, "carriage-to-fin guide clearance (0.3..1.0)")
    m = math.hypot(MOTOR_BCD / 2 * COS_S * 0 + MOTOR_BCD / 2 / math.sqrt(2), 0)
    m = CAR_W / 2 - (MOTOR_BCD / 2 / math.sqrt(2) + 4.0)
    ok(m >= 8.0, m - 8.0, "motor bolt boss inside carriage")
    for zp, mp_top, tag in ((ZL, MPL_TOP, "L"), (ZR, MPR_TOP, "R")):
        m = (zp - 1.5) - mp_top
        ok(m >= 2.0, m - 2.0, f"pulley lower flange clears carriage top ({tag})")

    # -- cradle / fins ------------------------------------------------------
    m = FIN_BI - belt_half(FIN_A_OUT)
    ok(m >= 3.0, m - 3.0, "outboard fin wall clear of belt corridor")
    m = FIN_BI - belt_half(FIN_A_INN)
    ok(m >= 3.0, m - 3.0, "inboard fin wall clear of belt corridor")
    # fin wall nearest corner vs the O113 driven pulley + flange
    fx, fy = local_to_world(1, FIN_A_OUT, FIN_BI)
    m = math.hypot(fx - HX, fy) - (PD_DRV / 2 + 3.5)
    ok(m >= 2.0, m - 2.0, "outboard fin end clears 72T pulley flange")
    for zp, mp_top, tag in ((ZL, MPL_TOP, "L"), (ZR, MPR_TOP, "R")):
        frame_top = mp_top - MP_T
        # datum is the pulley FLANGE bottom (zp - 1.5), which reaches 1.5 mm
        # below the belt band and sweeps over the block/nut footprint
        m = (zp - 1.5) - (frame_top + BLK_H)
        ok(m >= 2.0, m - 2.0, f"jack block top under pulley flange ({tag})")
        nut_top = frame_top + JACK_Z_OFF + 5.55       # M6 jam nut across corners
        m = (zp - 1.5) - nut_top
        ok(m >= 1.4, m - 1.4, f"jackscrew jam nut under pulley flange ({tag})")
    # inboard fin / flange forward ends respect the centreline clip
    m = -FIN_BO - clip_b(FIN_A_INN)
    ok(m >= 0.5, m - 0.5, "inboard fin end inside centreline clip")

    # -- centreline gaps -----------------------------------------------------
    # nearest carriage corner to x=0 is the front-inboard one at full travel
    car_x, _ = local_to_world(1, CAR_L / 2 + TENSION, -CAR_W / 2)
    ok(2 * car_x >= 3.0, 2 * car_x - 3.0, "left/right carriages gap at centreline")
    fp = frame_poly_local()
    fmin = min(local_to_world(1, a, b)[0] for a, b in fp)
    ok(fmin >= CL_MARGIN - 0.1, fmin - CL_MARGIN, "cradle frame at centreline clip")

    # -- CROSS-SIDE: the right frame (z 5..13 at MPR) shares the z-band of the
    # LEFT 72T pulley flange (zp-1.5 up) and the LEFT belt. Every frame point
    # (vertices + edge midpoints) must clear the opposite flange circle AND
    # the opposite belt's inboard strand. This is the one place the geometry
    # crosses sides — the straight centreline clip alone does NOT cover it.
    fpts = list(fp) + [((fp[i][0] + fp[(i + 1) % len(fp)][0]) / 2,
                        (fp[i][1] + fp[(i + 1) % len(fp)][1]) / 2)
                       for i in range(len(fp))]
    wpts = [local_to_world(1, a, b) for a, b in fpts]
    flange_r = PD_DRV / 2 + 3.5
    m = min(math.hypot(px + HX, py) for px, py in wpts) - flange_r
    ok(m >= 1.5, m - 1.5, "frame corner clears the OPPOSITE 72T flange sweep")
    # opposite belt inboard strand = outer tangent between the two belt-back
    # circles of the LEFT drive; clearance is the signed distance to that line
    c1, r1 = (-HX, 0.0), PD_DRV / 2 + 1.6
    c2, r2 = (-MXx, MXy), PD_MOT / 2 + 1.6
    dx, dy = c1[0] - c2[0], c1[1] - c2[1]
    D = math.hypot(dx, dy)
    alpha = math.acos(-(r1 - r2) / D)
    phi = math.atan2(dy, dx)
    n = max(((math.cos(phi + s * alpha), math.sin(phi + s * alpha))
             for s in (1, -1)), key=lambda v: v[0])   # inboard-pointing normal
    cline = n[0] * c1[0] + n[1] * c1[1] + r1
    m = min(n[0] * px + n[1] * py - cline for px, py in wpts)
    ok(m >= 1.5, m - 1.5, "frame corner clears the OPPOSITE belt strand")

    # -- deck containment (every underside part, 1.5 mm inside the outline) --
    pts = {}
    for a, b in fp:
        pts[f"frame({a:.0f},{b:.0f})"] = (a, b)
    pts["flangeO-rear"] = (-FR_A, FLG_B); pts["flangeO-frnt"] = (FIN_A_OUT, FLG_B)
    pts["flangeI-rear"] = (-FR_A, -FLG_B); pts["flangeI-frnt"] = (FIN_A_INN, -FLG_B)
    for cx in (-1, 1):
        for cy in (-1, 1):
            pts[f"carriage({cx},{cy})"] = (cx * (CAR_L / 2 + TENSION), cy * CAR_W / 2)
            pts[f"motor({cx},{cy})"] = (cx * 46.0, cy * 40.0)
    pts["block-out"] = (BLK_A1, BLK_B); pts["block-in"] = (BLK_A1, -BLK_B)
    worst, worst_k = 1e9, ""
    for k, (a, b) in pts.items():
        for sgn in (1, -1):
            d = _deck_margin(local_to_world(sgn, a, b))
            if d < worst:
                worst, worst_k = d, f"{k} side {sgn}"
    ok(worst >= 1.5, worst - 1.5, f"deck contains all hardware (worst: {worst_k})")
    # tool-access slots: inside the outline, clear of every circular deck hole
    holes = deck_hole_table()
    hl, hw = ACC_L / 2, ACC_W / 2
    worst_edge, worst_hole, worst_pair = 1e9, 1e9, ""
    for hid, sx_, sy_, ang in deck_access_slots():
        th = math.radians(ang)
        ux, uy = math.cos(th), math.sin(th)
        vx, vy = -math.sin(th), math.cos(th)
        for i in (-1, 1):
            for j in (-1, 1):
                worst_edge = min(worst_edge, _deck_margin(
                    (sx_ + i * hl * ux + j * hw * vx,
                     sy_ + i * hl * uy + j * hw * vy)))
        for hid2, hx_, hy_, d, _n in holes:
            px, py = hx_ - sx_, hy_ - sy_
            t = max(-(hl - hw), min(hl - hw, px * ux + py * uy))
            dd = math.hypot(px - t * ux, py - t * uy) - hw - d / 2
            if dd < worst_hole:
                worst_hole, worst_pair = dd, f"{hid}-{hid2}"
    ok(worst_edge >= 1.5, worst_edge - 1.5, "deck access slots inside the outline")
    ok(worst_hole >= 2.0, worst_hole - 2.0,
       f"deck access slots clear of deck holes (worst: {worst_pair})")

    xs = [p[0] for p in DECK_PTS]; ys = [p[1] for p in DECK_PTS]
    m = BED - (max(xs) - min(xs))
    ok(m >= 0, m, "deck width fits 300 bed")
    m = BED - (max(ys) - min(ys))
    ok(m >= 0, m, "deck depth fits 300 bed")
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

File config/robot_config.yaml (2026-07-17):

# Verified 5-bar geometry — the design point from Claude.md §3, §5.
# DO NOT silently revert any of these values. They came out of a full
# kinematic design review and supersede the original spec draft.

geometry:
  l1_mm: 200.0            # proximal link (shoulder -> elbow)
  l2_mm: 230.0            # distal link   (elbow -> TCP)
  base_spacing_mm: 80.0   # 3.15 in, symmetric (narrowed by inverting L motor)

assembly:
  # Best-conditioned branch (Claude.md §3.4): left elbow "up", right "down".
  left_elbow: up
  right_elbow: down

joint_limits:
  min_deg: -20.0
  max_deg: 200.0

drivetrain:
  # A6 EtherCAT servo: 17-bit absolute encoder = 131072 counts per motor rev.
  # In CSP the drive position unit is one encoder count, so this is the raw
  # feedback resolution, not a microstep count. Confirm against the drive's
  # position factor / electronic gearing at bring-up (docs/ethercat_bringup.md).
  pulses_per_rev: 131072  # A6M80-750 17-bit encoder counts / motor rev
  belt_reduction: 3.0     # 3:1 HTD-5M (20T motor -> 60T shoulder). NOTE: the A6M80
                          # has a 19 mm shaft, so a 20T GT3 (19.1 mm pitch dia) will
                          # NOT bore to 19 mm — use HTD-5M (20T pitch dia 31.8 mm).
  # pulses_per_degree = 131072 * 3 / 360 = 1092.2667 (derived, see config properties)

singularity:
  # Workspace guard thresholds (Claude.md §3.6, §9).
  parallel_min_deg: 20.0    # min degrees from the distal links being collinear
  serial_min_deg: 15.0      # min degrees from an arm being straight/folded
  reach_fraction_max: 0.85  # TCP distance / full reach (stiffness cap)

homing:
  # Home/limit switch reference — see docs/homing.md for the overhead figure.
  # The home flag is a small tab on the PROXIMAL link L1 (never L2) at
  # flag_radius_mm from the shoulder pivot; the switch mounts on a short base
  # bracket at the home trip angle and wires to the drive's homing digital input.
  # Both shoulders share the same trip angles. Mid-travel centre home
  # (TCP = home_tcp_mm). CiA 402 homing (mode 6) references to this switch and
  # zeros the drive there; the A6 absolute encoder then holds the datum.
  home_left_deg: 140.5406   # left shoulder angle at the home reference pose
  home_right_deg: 39.4594   # right shoulder angle at the home reference pose
  home_tcp_mm: [0.0, 250.0] # TCP these angles correspond to (informational)
  flag_radius_mm: 40.0      # tab radius on L1 (sensor bracket reaches to this)
  # Hard travel limits — mirror joint_limits above; wire the limit switches to
  # the drives' inputs and into the STO/E-stop safety chain.
  limit_min_deg: -20.0
  limit_max_deg: 200.0

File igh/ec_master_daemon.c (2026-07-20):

/* IgH EtherCAT RT master daemon for the 5-bar robot.
 *
 * Owns the DC cyclic loop (the config proven by igh_test) for 1-2 ANCTL AS715N
 * drives and exposes each drive's process image + a CSP setpoint buffer in POSIX
 * shared memory (/bcr_ethercat). The Python IgHMaster maps that memory and drives
 * the CiA 402 state machine / streams motion; this daemon is the RT transport.
 *
 * Usage:  sudo ./ec_master_daemon --drives 1 [--cycle-ns 2000000]
 * Stop:   set shm.stop = 1 (IgHMaster does this) or SIGINT.
 *
 * Shared-memory layout is mirrored byte-for-byte by igh_master.py (packed, LE).
 */

#include <stdio.h>
#include <stdlib.h>
#include <string.h>
#include <stdint.h>
#include <unistd.h>
#include <signal.h>
#include <time.h>
#include <fcntl.h>
#include <sys/mman.h>
#include <sched.h>
#include <pthread.h>

#include "ecrt.h"

#define VENDOR       0x00400000u
#define PRODUCT      0x00000715u
#define ASSIGN_ACT   0x0300
#define SYNC0_SHIFT  0
#define MAX_DRIVES   2
#define CSP_MAX      65536
#define SHM_NAME     "/bcr_ethercat"
#define SHM_MAGIC    0x42435231u   /* 'BCR1' */
#define SHM_ABI      5u            /* bumped: 0x60B1 velocity-offset FF stream */
#define LINK_RAW_SZ  20            /* ESC regs 0x0300..0x0313 in one read */
#define LINK_REG_ADDR 0x0300

#define NSEC_PER_SEC 1000000000L
#define TS2NS(T) ((uint64_t)(T).tv_sec * NSEC_PER_SEC + (T).tv_nsec)

#pragma pack(push, 1)
typedef struct {
    /* outputs: Python -> daemon */
    uint16_t controlword;
    int8_t   mode;
    uint8_t  _p0;
    int32_t  target_position;
    uint32_t digital_outputs;
    /* inputs: daemon -> Python */
    uint16_t statusword;
    int8_t   mode_display;
    uint8_t  _p1;
    int32_t  actual_position;
    int32_t  following_error;
    uint16_t error_code;
    int16_t  torque_actual;
    uint32_t digital_inputs;
} drive_shm_t;

typedef struct {
    uint32_t magic, abi, num_drives, cycle_dt_ns;
    uint64_t cycle_count;
    uint32_t wkc_bad, op, stop;
    uint32_t csp_start, csp_running, csp_len, csp_index;
    drive_shm_t drive[MAX_DRIVES];
    int32_t  csp[MAX_DRIVES][CSP_MAX];
    /* SDO channel (appended so existing offsets don't move): Python fills a
     * request and sets sdo_req; the SDO thread services it and sets sdo_done.
     * sdo_op 0 = download (write), 1 = upload (read into sdo_value). sdo_drive
     * selects the slave position. */
    uint32_t sdo_req, sdo_done;
    int32_t  sdo_result;                 /* 0 = ok, else abort/return code */
    uint32_t sdo_index, sdo_sub, sdo_size;
    int32_t  sdo_value;                  /* write: value in; read: value out */
    uint32_t sdo_drive, sdo_op;
    /* ESC link/CRC error counters (appended, ABI 4): the RT loop reads each
     * slave's registers 0x0300..0x0313 (~1 Hz) via an ecrt reg request and
     * publishes the raw 20 bytes; link_seq[d] increments per fresh snapshot.
     * Python sets link_reset=1 to zero the hardware counters (daemon writes
     * zeros over the register block and clears the flag when done). Raw byte
     * map: [0]=inv frame p0, [1]=rx err p0, [2]/[3]=p1, [8]/[9]=forwarded
     * p0/p1, [12]=PU err, [13]=PDI err, [16]/[17]=lost link p0/p1. */
    uint32_t link_reset;
    uint32_t link_seq[MAX_DRIVES];
    uint8_t  link_raw[MAX_DRIVES][LINK_RAW_SZ];
    /* Velocity-offset feedforward stream (ABI 5): parallel to csp[], the
     * per-cycle 0x60B1 velocity offset (counts/s) the RT loop writes while
     * streaming. Lets the drive feedforward OUR trajectory velocity (set the
     * drive's speed-FF source = Communication / C01.13=5) instead of
     * differentiating the position steps into a chirp. Zero when not streaming. */
    int32_t  csp_vel[MAX_DRIVES][CSP_MAX];
} shm_layout_t;
#pragma pack(pop)

/* RxPDO: the FLEXIBLE 0x1600 (ESI Fixed="0") so we can map 0x60B1 velocity
 * offset — 0x1701 is Fixed="1" and can't carry it. We drop the unused touch-
 * probe function (0x60B8) and add velocity offset. TxPDO 0x1B01 is unchanged. */
static ec_pdo_entry_info_t rx_entries[] = {
    {0x6040,0,16},{0x607A,0,32},{0x60FE,1,32},{0x60B1,0,32}};
static ec_pdo_entry_info_t tx_entries[] = {
    {0x603F,0,16},{0x6041,0,16},{0x6064,0,32},{0x6077,0,16},{0x60F4,0,32},
    {0x60B9,0,16},{0x60BA,0,32},{0x60BC,0,32},{0x60FD,0,32}};
static ec_pdo_info_t rx_pdos[] = {{0x1600, 4, rx_entries}};
static ec_pdo_info_t tx_pdos[] = {{0x1B01, 9, tx_entries}};
static ec_sync_info_t syncs[] = {
    {0, EC_DIR_OUTPUT, 0, NULL, EC_WD_DISABLE},
    {1, EC_DIR_INPUT,  0, NULL, EC_WD_DISABLE},
    {2, EC_DIR_OUTPUT, 1, rx_pdos, EC_WD_ENABLE},
    {3, EC_DIR_INPUT,  1, tx_pdos, EC_WD_DISABLE},
    {0xff}};

struct off {                       /* per-drive process-image byte offsets */
    unsigned ctrl, target, veloff, dout;
    unsigned err, status, pos, torq, ferr, tps, tp1, tp2, din;
};

static volatile sig_atomic_t running = 1;
static void on_sig(int s){ (void)s; running = 0; }

static ec_master_t *master;      /* file-scope so the SDO thread can use them */
static shm_layout_t *shm;

/* SDO worker: runs OFF the RT loop (SDO is a blocking mailbox op). Services one
 * request at a time; Python sets sdo_req and waits for sdo_done. Handles both
 * download (write, sdo_op=0) and upload (read, sdo_op=1), on the selected drive. */
static void *sdo_thread(void *arg)
{
    (void)arg;
    while (running) {
        if (shm->sdo_req && !shm->sdo_done) {
            size_t sz = shm->sdo_size ? shm->sdo_size : 4;
            if (sz > 4) sz = 4;
            uint16_t drive = (uint16_t)shm->sdo_drive;
            uint16_t idx = (uint16_t)shm->sdo_index;
            uint8_t sub = (uint8_t)shm->sdo_sub;
            uint32_t abort = 0;
            int ret;
            if (shm->sdo_op == 1) {                    /* upload (read) */
                uint8_t buf[4] = {0};
                size_t result_size = 0;
                ret = ecrt_master_sdo_upload(master, drive, idx, sub,
                                             buf, sizeof(buf), &result_size, &abort);
                if (!ret) {
                    int32_t v = 0;
                    memcpy(&v, buf, result_size > 4 ? 4 : result_size);
                    if (result_size == 1) v = (int8_t)v;       /* sign-extend */
                    else if (result_size == 2) v = (int16_t)v;
                    shm->sdo_value = v;
                }
            } else {                                   /* download (write) */
                uint8_t buf[4] = {0};
                int32_t v = shm->sdo_value;
                memcpy(buf, &v, sz);                   /* little-endian */
                ret = ecrt_master_sdo_download(master, drive, idx, sub, buf, sz, &abort);
            }
            shm->sdo_result = ret ? (int)(abort ? abort : (uint32_t)(-ret)) : 0;
            shm->sdo_done = 1;
        }
        usleep(1000);
    }
    return NULL;
}
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

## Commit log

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2026-07-06 Add pixel->robot calibration + wire cover reachability
    vision/calibration.py (Claude.md §13):
    - CameraIntrinsics: pinhole K + Brown-Conrady distortion, undistort_points,
    from_yaml/from_dict (optional; null skips undistortion).
    - HomographyTransform: undistort -> homography -> robot-frame mm.
    from_correspondences (>=4 pts, least squares, reports RMS residual_mm),
    from_matrix, pixel_to_robot(_many), robot_to_pixel_many, save/load .npy.
    - CalibrationManager: fixed cover-plane transform + per-recipe battery-top
    transforms, persisted as calibration/*.npy (git-ignored); clear errors when
    missing.
    - config/camera_config.yaml: optional intrinsics block.
    GUI:
    - gui/imaging.py demo_transfo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
    [camera_config.yaml]
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2026-07-06 Give each recipe its own calibration data
    Make recipes first-class (battery types) and attach a pixel->robot
    calibration to each. A changeover selects the recipe and loads its own
    homography + vent-hole count for the whole cycle.
    - app/recipes.py + config/recipes.yaml: Recipe (key, name, hole_count,
    cover_diameter_mm) + RecipeStore (load/add/persist YAML). Seeds g31-6/g24-6.
    - vision/calibration.py: CalibrationManager is now per-recipe — has/get/save/
    keys keyed by recipe, stored at calibration/<key>.npy (was cover.npy /
    battery_<key>.npy).
    - gui/calibration_tab.py: recipe selector replaces the cover/battery plane
    combo; shows whether the recipe is calibrated; "Add" creates a new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
    [recipes.yaml]
2026-07-06 Wire per-recipe cover-size gating + live recipe-list refresh
    Close the two loose ends from the per-recipe calibration work.
    Cover-size gating: each recipe's cover_diameter_mm now filters detection.
    - vision/detect_covers.py: CoverDetectorConfig gains expected_diameter_mm +
    diameter_tolerance. When a calibration is present, each blob's real diameter
    is measured (mean of x/y spans through the transform) and blobs off the
    nominal size are rejected as "wrong size". 0 or no-calibration disables it.
    - gui/vision_tab.set_cover_diameter_mm rebuilds the detector; main_window
    applies it on changeover alongside hole_count + calibration.
    Live recipe-list refresh: adding a recipe in the Calibra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
    [recipes.yaml]
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2026-07-06 Split UDT into per-type L5X (leaves-first) and switch tags to CSV
    Two import fixes based on what Studio 5000 actually accepts:
    UDT import failed with "error creating 'member' ... data type was missing".
    Root cause: the combined single-file export (one Use="Target" + Use="Context"
    leaves) did not reliably CREATE the nested types, so the parent VisionRobot
    referenced types that didn't exist yet. Fixed by exporting one data type per
    file as its own Target, imported leaves-first:
    1_VisionRobot_Cmd.L5X .. 4_VisionRobot_Status.L5X (leaves), then
    5_VisionRobot.L5X (parent, references the four).
    Tags are now a Rockwell tag CSV (RobotTags.csv) instead of L5X — the format
    Logix's bulk tag impo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
    [RobotTags.csv]
2026-07-06 Expand RobotTags.csv to the whole program's tags (38 -> 86)
    The CSV only carried the glue for the three shipped motion routines. Added
    every remaining controller-scope tag the full program references, grouped by
    routine and pulled from plc_ladder.md / plc_homing.md:
    - safety (R10): EStop_Pressed/OK, Guard_Closed, Ax*_LimitMin/Max, SafetyOK,
    EnableReq, Reset_prev
    - drives (R20): Ax0/1_Ready
    - manual (R40): AutoMode, WithinLimits, MoveActive, MTT_prev
    - auto pick/place (R50): State, RPP_prev/AR_prev, VacTmr/BlowTmr (TIMER),
    Cmd*/At*/Arrived, AutoTL/TR/AutoMove, poses PickL/R DropL/R,
    pneumatics CylinderDown/VacuumOn/Blowoff, Z sensors PickDown/Up DropDown/Up,
    VacuumSensor
    - config/pos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
    [RobotTags.csv]
2026-07-06 Fix RobotTags.csv so Studio 5000 actually imports it
    Two things were making Logix import nothing from the tag CSV:
    - Empty SCOPE column. The import routes tags by scope; a blank scope imports
    nothing. Now every row carries SCOPE = the controller name (default
    RobotController; override with `python scripts/render_plc_l5x.py MyController`
    or find/replace, or use the import dialog's ignore-scope option).
    - LF line endings. The file was generated on Linux (LF); Studio 5000 on Windows
    needs CRLF or it parses nothing. The CSV is now written with CRLF (as bytes so
    it survives verbatim) and marked `-text` in .gitattributes so git won't
    normalize it on checkout.
    Also dropped a "<=" from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
    [RobotTags.csv]
2026-07-06 Match RobotTags.csv to a real Logix v34 export so it imports
    Grounded the tag CSV in an actual export from the target controller
    (docs/Bung_Cover_Controller_Tags.CSV on main). Earlier guesses were missing the
    format essentials; corrected to match byte-for-byte:
    - Added the "0.3" format-version line between the remark preamble and the header
    (Logix imports nothing without it — this was the main blocker).
    - SCOPE column is empty for controller tags (a real export leaves it blank);
    reverted the earlier controller-name-in-scope change.
    - Quote DESCRIPTION, DATATYPE, SPECIFIER, and ATTRIBUTES; keep NAME bare.
    - Attribute order RADIX, Constant, ExternalAccess; structured tags (TIMER, the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
    [RobotTags.csv]
2026-07-06 Fix homing timer: TONR is ST-only; use a gated ladder TON
    TONR is an IEC (Structured Text / Function Block) timer — invalid in the neutral
    ladder text of R_HomeMotor0/1. The retentive ladder timer is RTO, but a timeout
    shouldn't be retentive: replaced it with a non-retentive TON gated on the active
    homing states (NEQ(State,0) LES(State,70)), so it auto-resets when homing
    completes/faults/idles and each attempt starts fresh.
    Also fixed a latent bug this exposed: CSV import leaves Home*_Tmr.PRE = 0, which
    would make DN true immediately and fault every homing attempt. Added a
    MOV(HOME_TMO_MS, Home*_Tmr.PRE) rung and a HOME_TMO_MS tag (default 15000 ms) so
    the preset is always loaded.
    Co-Aut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
    [RobotTags.csv]
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2026-07-07 Add the full PLC program: R00_Main dispatcher + R10/R20/R40/R50/R60
    Previously only the motion pieces (R_Move/R_Home, R30_Homing) and the tags were
    shipped, so nothing tied them together in Studio 5000 and there was no auto
    program. Added the routines that make it a complete, importable program:
    - R00_Main: scan dispatcher, JSRs everything each scan; Manual vs Auto on the
    AutoMode tag. Set it as the Program's Main.
    - R50_Auto: the §11 automatic pick/place state machine (camera-clear -> pick ->
    vacuum + verify -> drop -> blowoff -> complete), with VacTmr/BlowTmr.
    - R10_Safety, R20_Drives, R40_Manual, R60_Status.
    Architecture fix: R20_Drives is now the sole owner of the axis Enable outp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
    [RobotTags.csv]
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2026-07-07 Add Reset + fault handling to the Robot Test HMI and R30 recovery
    Reported: no Reset button, lots of fault code 4 with no recovery, no message when
    homing fails, and the Enable button stays highlighted after a failed enable.
    Audited the enable/home/reset/fault path across GUI, controller, driver, and
    ladder; fixes across all four layers:
    Driver (robot/driver.py, plc/plc_robot_driver.py):
    - Add reset() (pulses the previously-dead VisionRobot.Cmd.Reset and waits for the
    fault to clear), is_faulted, and fault_code() to the ABC + both impls.
    - Normalize PlcError -> RobotDriverError in enable/home/move/stop/reset so the
    documented boundary type actually holds (a comms drop no longer escapes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
    [RobotTags.csv]
2026-07-07 Add a bench Bypass tab: force safeties, skip homing, bypass vision sensors
    For bench-testing motors before the machine is built, a new GUI Bypass tab feeds
    the PLC the inputs the missing hardware would provide (writes to the connected
    real or simulated PLC):
    - Force safeties SAFE: writes the safety INPUT tags (EStop_OK=1, Guard_Closed=1,
    limits/alarms=0) so the drives enable with no safety I/O. The safety logic is
    untouched — aliasing those tags to real inputs later overrides the bench values.
    - Bypass_Homing (new ladder tag): R30 marks referenced instantly on HomeRequest
    and publishes HOME_ANGLE_L/R (no home prox needed), so you can jog.
    - Bypass_Vision (new ladder tag): R50 auto-s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
    [RobotTags.csv]
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2026-07-07 Homing: require real motion before accepting Has_Homed
    The per-axis homing latched Ax_HomeDone purely off the ClearLink
    Has_Homed status level at State 60. Has_Homed (bit 13) latches once a
    reference exists and persists across a PLC-only restart / can read set at
    power-up, so the state machine could walk 0->60, see a stale level, and
    complete a home with no motion and no prox trip.
    Gate completion on Home{m}_Moved, latched from Status_Steps_Active
    (bit 1) only while the homing move runs (States 50-60) and cleared at the
    start of each attempt. If the axis never steps (HOME_VEL still 0, Homing
    Enable not configured, drive not wired) Has_Homed can no longer
    false-complete the home -- it times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
    [RobotTags.csv]
2026-07-07 Fix move deadlock: level-trigger the load instead of an Execute edge
    Move{m}_Execute is a sticky latch (R40/R50 OTL it and only clear it on
    move completion or abort). R_MoveMotor loaded the position move on the
    RISING EDGE of Move{m}_Execute via ONS. If the first load was ever missed
    -- e.g. a transient Shutdowns_Pres present at the edge blocks the rung
    output while the one-shot still consumes the edge -- Move{m}_Execute stays
    latched at 1 forever (the move never completes), so the one-shot can never
    re-fire. R40 re-latching an already-1 bit produces no new edge, so every
    later jog/move is silently ignored: Move{m}_Execute stuck 1,
    Load_Posn_Data never pulses, 10 s timeout with no fault.
    Lo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
    [RobotTags.csv]
2026-07-07 Fix no-HLFB drive: correct HLFB Inversion guidance + bench shutdown clear
    Diagnosis from the ClearLink EtherNet/IP reference + live registers: with a
    no-HLFB third-party drive (EM806), the docs told users to set HLFB Inversion
    (Config Register bit 3) = 1. That makes the ClearLink read HLFB de-asserted,
    so Motor In Fault (Status bit 9) latches, which cancels all motion and sets
    a Motor Faulted shutdown (Shutdowns bit 10) -- the axis holds, no step pulses
    emit, moves silently time out. Confirmed on hardware (Status bit 9/17 set,
    bit 10/14 clear; Shutdowns bit 10 set). Per the manual's third-party
    troubleshooting (p.72) HLFB Inversion must be OFF (0) for a drive with no
    HLFB. Corrected every do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
    [RobotTags.csv]
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2026-07-08 Add PC<->PLC heartbeat watchdog (dead-man) + startup reconciliation
    An app connecting to already-enabled drives with no liveness contract is a
    safety gap. Add a bidirectional heartbeat:
    - PC->PLC: PlcRobotDriver runs a background thread incrementing
    Cmd.Heartbeat every 0.2s while connected (start on connect, stop on close).
    - PLC watchdog (R10): HB_Tmr (preset HB_TIMEOUT_MS ~1s) resets on each
    Cmd.Heartbeat change; on expiry Status.PcAlive drops and, if Enable was
    requested, latches FaultCode 10 (code 10 was referenced but never built).
    - Enable gated on PcAlive (R20): EnableReq = Manual.Enable . SafetyOK .
    !Faulted . PcAlive -- the drives can't be enabled or stay enabled without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
    [RobotTags.csv]
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2026-07-08 Reset now clears the ClearLink drive fault, not just the PLC latch
    After a drive alarm (EM806 ALM wired to HLFB -> Motor_In_Fault, Status
    bit 9), hitting Reset cleared VisionRobot.Status.Faulted but never told
    the ClearLink to clear its own motor fault + shutdown, so R10 re-latched
    the fault every scan and the machine was stuck (b9 stayed on even after
    the HLFB was restored).
    - R_HomeMotor State-20 (Clear Fault) and State-30 (Clear Alerts) coils
    now also fire on VisionRobot.Cmd.Reset, so a plain reset commands the
    ClearLink to clear bit 9 and the OR-accumulating Motor-Faulted shutdown
    without needing to run a home. These routines scan every cycle, so the
    coils evaluate during a plai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
    [RobotTags.csv]
2026-07-08 Correct the drive-fault-clear model: bit 9 is real-time, not latched
    The previous commit assumed ClearLink Motor_In_Fault (Status bit 9) was a
    latched fault needing a Clear-Motor-Fault enable cycle. Re-reading the
    manual against the actual EM806 wiring, that premise is wrong and an
    enable-cycle approach would be unsafe:
    - Motor Status is a "real time register"; bit 9 = (HLFB de-asserted AND
    Enable output asserted), purely combinational. It falls on its own the
    instant HLFB returns or the Enable output drops -- no enable cycle, and
    forcing the Enable output on while HLFB is de-asserted would actively
    re-create bit 9 and energize a possibly-alarmed drive.
    - The genuinely latched objec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
    [RobotTags.csv]
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2026-07-08 Clear a latched Motor Fault via an HLFB-gated enable cycle
    Hardware data settled the question: with the drive healthy (HLFB restored,
    b14=1) and no shutdown present (b17 off), Motor_In_Fault (Status bit 9)
    stays latched and Clear Alerts does not touch it. That matches the manual:
    a Motor Fault sets when HLFB de-asserts while enabled and clears ONLY via
    Clear Motor Fault (Output bit 7) -- a momentary disable/re-enable ENABLE
    CYCLE, which is a no-op unless the Enable output is asserted. Anti-restart
    holds the enable off while Faulted, so the cycle never runs -> deadlock.
    (This supersedes the prior "bit 9 is real-time, needs no enable cycle"
    reading, which the bench data disproves.)
    Fix -- R20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
    [RobotTags.csv]
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2026-07-09 Lock in coplanar geometry: L1=200, L2=230, base spacing 80 mm
    Retune the verified design point to the stiffer, better-conditioned
    coplanar (up/down) build: a shorter proximal link and a narrower base
    (reachable by inverting the left motor). Recompute the home pose
    (L 140.5406 / R 39.4594 deg at TCP 0,250) and propagate it through the
    kinematics defaults, robot_config.yaml, the PLC constant generator, and
    the regenerated tag exports. Retarget the work-zone tests to the new
    envelope (13 in-wide part footprint) and relax two TCP asserts for pulse
    quantization. Refresh the geometry/home numbers across the docs.
    Claude-Session: https://clau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
    [RobotTags.csv, robot_config.yaml]
2026-07-09 Seed HOME_OFFSET_L/R with nominal values (3748 / 1052)
    Default the home-offset constants to the computed nominal
    (switch_angle * STEPS_PER_DEG) instead of 0, so a fresh push or Studio
    import gives a sane home reference out of the box; refine on the machine
    at commissioning. Updated in both the L5X generator and the runtime
    constant registry (drift-guard stays green) and regenerated exports.
    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
    [RobotTags.csv]
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2026-07-09 Recipe: separate bung-cover vs drop-hole diameters; show holes in Detect
    A shouldered bung cover is wider than the hole it seats in, so one diameter
    can't gate both. Add hole_diameter_mm to Recipe (separate from
    cover_diameter_mm), a 'Hole diameter' field in the recipe editor, and a
    physical mm size gate on HoleDetector (expected_diameter_mm + tolerance via
    to_robot). Bring drop holes back into the Detect overlay behind a 'Show drop
    holes' toggle (on by default), gated on the recipe's hole diameter.
    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
    [recipes.yaml]
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2026-07-09 Vision: scrollable sidebar, per-recipe detection sliders, live auto view
    Three main-screen fixes:
    - Scrollable sidebar: the mode/run/pick-region/tuning stack is tall, so wrap
    it in a QScrollArea — groups no longer overlap/clip on a short window.
    - Detection sliders save per recipe: Recipe gains cover_min/max_px, hough_edge,
    hough_votes, hole_min/max_px. A changeover loads them into the sliders
    (set_detection_tuning, applied before size/count so the windows come from the
    recipe), and releasing a slider persists them back to recipes.yaml.
    - Live view during the auto cycle: CycleManager.run_cycle takes an on_frame
    callback and the vision target source exposes last_frame; the work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
    [recipes.yaml]
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2026-07-09 R50_Auto: return the arm to a fixed PARK pose at the end of every cycle
    Root cause of "robot doesn't return to origin / seems to increment each cycle":
    R50_Auto's last motion was State 130 MOVE_ABOVE_DROP; State 200 COMPLETE_JOB did
    only housekeeping, so the arm was left sitting at the last vision-supplied DROP
    pose. Because holes fill left-to-right, each cycle ended at a different spot and
    the next cycle's move to CAMERA_CLEAR read as an unexplained/"incrementing" extra
    move. (An exhaustive multi-agent audit of all motion subsystems confirmed this as
    the single root cause; every verifier refuted a per-cycle code accumulation —
    moves are absolute and no register aliases a counter.)
    - Add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
    [RobotTags.csv]
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2026-07-10 Auto: park to HOME_ANGLE (drop the PARK footgun) + safe CAMERA_CLEAR default
    Field diagnosis: an auto cycle ended at shoulder angles 0,0 (TCP 200,226) and
    re-running gave the same commanded numbers at a different PHYSICAL place, and a
    manual home afterward was wrong. Root cause: CAMERA_CLEAR_L/R and PARK_L/R were
    left at 0 (the CSV import creates tag definitions only — values are set by hand
    after import, and these two poses weren't). A 0 pose target commands a full-speed
    ~140-deg swing to 0 deg at the start and end of every job; the open-loop steppers
    skip steps on that big fast move, so the physical position drifts run-over-run
    (the "increment") and the datum is corrupted. Manual never c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
    [RobotTags.csv]
2026-07-10 Auto moves: settle before "in position" (fix cut-short chained moves) + bench dwell
    Why the pick routine came off home, stopped once, and returned home without
    placing: R_MoveMotor latched Move*_InPosition the moment ClearLink At_Target_Posn
    read true, but right after a load-ack that bit can still be the PREVIOUS move's
    at-target (stale/at-rest). In auto the moves chain rapidly (in Bypass_Vision the
    pneumatic waits are instant), so each move "arrived" before it moved and the next
    state cancelled it mid-flight — the arm never reached pick/drop. Manual never
    chains moves, so it was always fine.
    - R_MoveMotor: add a MOVE_SETTLE_MS post-load settle (Move*_SettleTmr). InPosition
    can't latch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
    [RobotTags.csv]
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2026-07-16 Set drivetrain to the A6 servo (17-bit encoder) for correct deg<->counts
    The robot moved from open-loop steppers to StepperOnline A6 EtherCAT servos,
    so the drivetrain resolution changes: the drive's CSP position unit is one
    encoder count (17-bit = 131072 counts/motor rev), not a 3200-pulse microstep.
    - FiveBarConfig default and config/robot_config.yaml: pulses_per_rev
    3200 -> 131072 (belt stays 3:1). pulses_per_degree becomes 1092.267, the
    factor the trajectory planner and EtherCAT driver share to convert shoulder
    degrees to drive counts, so moves land at the right angle. ~0.0009 deg/count.
    - test_kinematics: assert the new pulses_per_degree (the from-yaml==defaults
    guard keeps the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
    [robot_config.yaml]
2026-07-16 robot_config: belt note HTD-5M (A6M80 19mm shaft won't take a 20T GT3)
    The A6M80-750 has a 19 mm output shaft; a 20-tooth GT3 pulley (19.1 mm pitch
    diameter) cannot be bored to 19 mm. Keep the 3:1 but switch the belt profile
    to HTD-5M (20T pitch dia 31.8 mm) so the motor pulley actually fits. No change
    to belt_reduction (still 3.0) or the deg<->counts math.
    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
    [robot_config.yaml]
2026-07-17 cad/: parametric CAD (CadQuery) with cross-plane nested distals
    Add the mechanical design as regenerable source, tied to the software's
    source of truth: link lengths, base spacing, and the home pose come from
    FiveBarConfig/FiveBarKinematics, and the link-collision proof sweeps the
    same WorkspaceValidator the runtime uses.
    Level assignment reworked to the cross arrangement (distal of one side
    pairs with the proximal of the other): plane A = proximal L + distal R,
    plane B = proximal R + distal L. The two proximals can never collide
    (different planes), the two distals stack naturally at the TCP (full-height
    bosses, shared pin + 5mm spacer, no lap machining), and a build-time sweep
    asserts the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
    [distal_arm.step, dual_base_full.step, proximal_arm.step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]
2026-07-17 cad/: fix D-joint alignment, clamp slit, shaft-top flat; 2x pinch bolts
    Three real defects caught in review of the generated model, plus one request:
    - Shoulder D-flat alignment: the arms are placed at their home angles but the
    shafts were not rotated with them, so the shaft's round side interfered with
    the arm's D-bore (522 mm^3 of overlap). Each shaft now rotates with its
    arm's home angle; the mate is verified numerically (0.00 mm^3 overlap).
    - Split-clamp slit: the slit box stopped 1.75 mm short of the pin bore, so the
    clamp could never compress. It now runs from outside the boss through the
    bore center, cut taller than the boss.
    - Shaft-top flat: the D-flat cut ended 1 mm belo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
    [distal_arm.step, dual_base_full.step, proximal_arm.step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]
2026-07-17 cad/: hollow TCP spindle — miniature air cylinder through the joint axis
    Replace the solid O8 TCP pin with a hollow O20/O16 spindle riding in two
    6804-2RS (20x32x7) bearings, one in each distal's OUTER face for maximum
    span (the plane-A distal is the same part flipped about its long axis).
    A miniature air cylinder (default ISO 6432 O10 bore, O15 barrel — set
    CYL_BARREL_OD for a different cylinder) drops through the spindle bore and
    clamps with a collar; the rod + vacuum cup exit below ON the joint axis,
    which makes the cup immune to the TCP platform's free spin. Barrel and
    port remain accessible above the collar (single-acting assumed; README
    notes the double-acting options).
    TCP boss g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
    [distal_arm.step, dual_base_full.step, proximal_arm.step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]
2026-07-17 cad/: rigid shear-wall motor mounts; belt tension moves to slotted plates
    Review feedback: the old design slid the whole hanging motor assembly on
    slots in the base plate for belt tension, leaving four O10 posts to resist
    the belt pull — unstable, and it cluttered the motor plate with corner
    standoff holes.
    Inverted: the mount is now rigid and FIXED, and the MOTOR is the adjustable
    element.
    - Motor plate: the O70 pilot bore and the four O90-BCD flange holes become
    +/-4 mm slots along the belt direction — loosen, slide the motor,
    tension, clamp. Slot width keeps the motor Y-registered so belt tracking
    alignment is preserved. Corner standoff holes gone.
    - Mounts: two 10 mm shear wa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
    [distal_arm.step, dual_base_full.step, proximal_arm.step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]
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2026-07-19 feat: guarded single-axis bench jog (enable + trapezoidal CSP ramp)
    Safety cage + E-stop->contactor is in place, so add the jog:
    - daemon: while a drive is NOT Operation Enabled, command target=actual
    so enabling never lurches toward a stale setpoint (CSP enable-jump).
    - trajectory.ramp_counts(): trapezoidal 1-D count ramp (a step would
    fault CSP on following error, so even a jog must ramp).
    - EtherCatRobotDriver.enable() now seeds target=actual too (belt +
    suspenders, and correct for the sim); jog_counts(drive, delta, speed)
    ramps one axis while the others hold, streamed via run_csp.
    - SimulatedEtherCatMaster.run_csp() handles a variable drive count (was
    hardcoded to two), so sin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
    [ec_master_daemon.c]
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
